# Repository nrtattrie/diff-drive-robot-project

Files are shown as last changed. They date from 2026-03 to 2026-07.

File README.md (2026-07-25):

# Diff-Drive Robot Project

A ROS 2 autonomous mobile robot project built in stages: differential-drive
navigation first, followed by a separately validated self-balancing controls
phase. The project emphasizes simulation, embedded motor control, encoder
odometry, sensor fusion, SLAM, Nav2, and disciplined hardware bring-up.

## Project Status

**Phase 1 — Foundation**

- Stage 1 software simulation is complete.
- The URDF, tf2 model, Gazebo Harmonic `DiffDrive`, and
  `ros2_control + diff_drive_controller` paths have been live-verified.
- Stage 2A hardware architecture is complete; Stage 2B now builds and validates
  the robot one subsystem at a time.
- A modular drivetrain deck follows one-channel acceptance. Final
  electronics-tier CAD remains gated on the two-channel, peripheral, and
  Pi-power checks.
- LiDAR and battery procurement remain deferred until the navigation hardware
  stage.

The historical hardware plan contained invalid assumptions, including treating
one Pololu `#2991` as a dual motor driver. Do not build from archived summaries
or the invalidated power diagram. See the
[component selection audit](hardware/component-selection-audit.md) and
[phase plan](docs/phases.md).

## Current Platform

### Compute and control

- Raspberry Pi 5, 8 GB
- Ubuntu 24.04 Desktop
- ROS 2 Jazzy
- NVMe boot through Raspberry Pi M.2 HAT+
- Arduino Due as the planned real-time motor/encoder controller
- Arduino Mega 2560 retained as a backup/prototyping controller

### Owned actuation and sensing

- 2× Pololu 50:1 37D 12 V gearmotors with 64 CPR encoders (`#4753`)
- 80 mm Pololu wheels and 6 mm mounting hubs
- Pololu Dual VNH5019 Motor Driver Shield (`#2507`) received for the two motor
  channels; physical identity was owner-accepted at B1, while assembly and
  powered bench acceptance remain pending
- 1× owned Pololu G2 High-Power Motor Driver 18v17 (`#2991`), reserved for
  later one-channel use rather than combined with the selected driver
- Adafruit BNO055 IMU
- Adafruit `#2998` bus-powered USB 2.0 hub, assigned to the BNO055/`#954`
  branch with the Due kept on a direct Pi port
- Raspberry Pi Camera Module 3
- HC-SR04 and other kit sensors for supplementary experiments
- RPLidar A1-class LiDAR planned for the autonomous-navigation stage

### Hardware constraints under validation

- Use commercial off-the-shelf boards, connectors, and wire. User soldering of
  supplied headers and ordinary wiring is acceptable; custom/professional
  assembly is outside the hobbyist project scope. Crimping is not assumed, so
  prefer solder, screw-terminal, lever-clamp, or pre-terminated connections as
  appropriate to the circuit.
- The encoders will use a regulated 5 V rail and one socketed Adafruit
  `74LVC245` product `#735` to translate their four outputs to the Due's 3.3 V
  hardware quadrature inputs; physical assembly and count-integrity bench
  acceptance remain pending.
- The Due will receive both power and serial through its Programming USB port,
  normally from the Pi, and will supply encoder 5 V and translator/driver-logic
  3.3 V. Bench current and reset behavior remain to be validated.
- Mobile Raspberry Pi power will use a protected 3S branch through the owned
  DROK set to 5.10 V and into the Pi 5 V/ground header; regulation, thermal,
  startup, and combined-load acceptance remain pending. Q8 selects one 10 A
  main fuse without additional branch-protection hardware. Q9 selects 16 AWG
  battery-side wiring, the 14 AWG inline fuse holder, continuity-checked
  ALITOVE distribution, and four short parallel Elegoo leads for Pi power;
  owned JST/STEMMA or Elegoo leads cover low-current wiring downstream of the
  Pi. The completed Q10 matrix fixes the final connection and pin allocation,
  while Stage 2B must reject any connection with excessive drop, heating,
  looseness, or reset behavior.
- The owned motors and 80 mm wheels are required Phase 2 reuse while plausible;
  preliminary dynamic screening supports that plausibility. All other Phase 2
  properties and reuse decisions remain intentionally deferred.

## Software Stack

- ROS 2 Jazzy on Ubuntu 24.04
- Gazebo Harmonic
- `ros2_control` and `diff_drive_controller`
- Nav2 and `slam_toolbox` planned for autonomous navigation
- `robot_localization` planned for encoder/IMU fusion
- Python for ROS integration and C++/Arduino code where real-time performance
  matters

## Repository Structure

```text
diff-drive-robot-project/
├── docs/                   Project architecture, phases, guides, and audits
├── hardware/               BOM, CAD exports, and hardware references
├── media/                  Images and other media
├── scripts/                Development and launch helpers
└── software/
    ├── arduino/            Embedded firmware
    └── ros2_ws/            ROS 2 workspace
```

## Build the ROS 2 Workspace

```bash
cd software/ros2_ws
colcon build
source install/setup.bash
```

For the verified simulation workflows, follow the
[Gazebo simulation quickstart](docs/gazebo_sim_quickstart.md).

## Roadmap

1. Execute the ordered Stage 2B assembly gates: Due and encoders, one motor
   channel, modular drivetrain, then both channels.
2. Validate the Pi/Due link, BNO055, camera, DROK, and complete Pi-power path.
3. Build the final electronics tier and tethered harness, then close the
   hardware gate with integrated and loaded thermal evidence.
4. Drive the real differential-drive robot and calibrate odometry.
5. Add LiDAR, SLAM, Nav2, and IMU fusion.
6. Model and validate the separate self-balancing conversion before committing
   Phase 2 hardware.

## Documentation

- [Architecture](docs/architecture.md)
- [Phase plan and task tracker](docs/phases.md)
- [Component selection audit](hardware/component-selection-audit.md)
- [Stage 2 hardware decision record](hardware/stage-2-hardware-decision-record.md)
- [Phase 1 power and signal interface matrix](hardware/power-signal-interface-matrix.md)
- [Stage 2 validation log](hardware/stage-2-validation-log.md)
- [Phase 2 preliminary dynamic model](hardware/phase-2-dynamic-model.md)
- [Gazebo simulation quickstart](docs/gazebo_sim_quickstart.md)
- [Assembly guide](docs/assembly.md)
- [Hardware BOM PDF](hardware/Bill%20of%20Materials%20-%20Sheet%20REV%2002.pdf)

## License

MIT License. See [LICENSE](LICENSE).

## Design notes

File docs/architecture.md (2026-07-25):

# Robot Architecture

## Directive for AI Assistants

This document is the canonical record of architectural decisions, technical
constraints, and design rationale. See [the phase plan](phases.md) for task
status, [the Stage 2 decision record](../hardware/stage-2-hardware-decision-record.md)
for selection evidence, and
[the interface matrix](../hardware/power-signal-interface-matrix.md) for exact
power, pin, connector, wire, threshold, and safe-state definitions.

Use this document before proposing or implementing changes. Do not modify it
unless explicitly asked. Do not treat archived summaries as current design
authority.

**Architecture status as of 2026-07-23:** Stage 2A is complete. The architecture
below is the selected design for the incremental Stage 2B build and
commissioning sequence. It is not yet a bench-validated final build. If a
statement here conflicts with the interface matrix, use the matrix for
connection-level details and resolve the discrepancy before wiring.

## Phase 1 System Overview

Phase 1 is an indoor differential-drive robot intended to progress from
tethered driving to encoder odometry, SLAM, and Nav2 autonomous navigation.

```text
Nav2 / teleop / ROS 2
          |
          v
   Raspberry Pi 5
      |       |---------------- Camera Module 3 (CSI-2)
      |       |---------------- #2998 hub -- BNO055 (USB-to-UART)
      |       `---------------- future RPLidar A1M8 (USB)
      |
      `--- USB serial + power ---> Arduino Due
                                      |
                         +------------+------------+
                         |                         |
                         v                         v
                  Dual VNH5019               encoder inputs
                    #2507                  through 74LVC245
                         |                         ^
                         v                         |
                    two #4753 motors --------------+
```

The Pi owns ROS 2, navigation, perception, and high-level velocity commands.
The Due owns real-time motor output, encoder counting, command-loss handling,
and motor-fault response. The Pi and Due communicate over one data-capable USB
connection to the Due Programming port.

## Selected Hardware Baseline

| Component | Selected role | Stage 2A state |
|---|---|---|
| Raspberry Pi 5, 8 GB | Primary computer running Ubuntu 24.04 and ROS 2 Jazzy | Owned; operating |
| 1 TB NVMe SSD and M.2 HAT+ | Pi boot and project storage | Owned; operating |
| Raspberry Pi Active Cooler | Pi thermal management through the dedicated fan connector | Owned; operating |
| Arduino Due | Real-time motor controller and hardware quadrature counter | Owned; bench integration pending |
| Pololu Dual VNH5019 shield `#2507` | Two-channel motor driver, separately mounted rather than stacked as a shield | Received; identity owner-accepted at B1; assembly/bench validation pending |
| 2x Pololu `#4753` 12 V, 50:1 gearmotors | Left and right Phase 1 drive, with integrated encoders | Owned |
| 80 mm Pololu wheels and 6 mm hubs | Drive wheels | Owned |
| Adafruit `74LVC245` `#735` and 20-pin socket | Four-channel 5 V-to-3.3 V encoder translation | Received; identity owner-accepted at B1; assembly/validation pending |
| Adafruit BNO055 `#4646` | IMU for later odometry fusion | Owned; UART validation pending |
| Adafruit USB Mini Hub with Power Switch `#2998` | Bus-powered expansion for the low-current BNO055/`#954` branch; three downstream sockets remain spare | Owned; integration validation pending |
| Raspberry Pi Camera Module 3 | Forward camera | Owned with Pi 5-compatible cable |
| DROK adjustable buck converter | Mobile Pi 5 V supply | Owned; exact-unit and loaded validation pending |
| Official Raspberry Pi 27 W USB-C supply | Bench/tethered Pi supply | Owned |
| RPLidar A1M8 development kit | Planned Phase 1 SLAM/Nav2 sensor | Deferred to Stage 4 |
| 3S battery, charger, and mating connector | Future mobile energy source | Deferred to Stage 4 |
| Pololu G2 18v17 `#2991` | Reserved one-channel driver; not part of the Phase 1 baseline | Owned |
| Arduino Mega 2560 | Backup/prototyping MCU only | Owned |

[BOM REV 02](../hardware/Bill%20of%20Materials%20-%20Sheet%20REV%2002.pdf)
is the accepted procurement snapshot. Procurement status does not constitute
bench validation.

## Power Architecture

### Selected topology

```text
future 3S battery (11.1 V nominal, 12.6 V full)
  |
  +-- keyed battery connector (manual disconnect)
  |
  +-- 10 A ATO/ATC fuse near battery positive
        |
        `-- ALITOVE distribution
              |
              +-- 16 AWG --> #2507 VIN/GND --> left/right motors
              |
              `-- 16 AWG --> DROK set to 5.10 V --> Pi 5 header
                                                        |
                                                        `-- USB --> Due
                                                                     |
                                                                     +-- 5 V --> both encoders
                                                                     `-- 3.3 V --> 74LVC245 and #2507 VDD
```

### Bench and mobile modes

- **Bench/tethered:** use the official 27 W USB-C supply for the Pi. The Pi
  powers and communicates with the Due over USB. A current-limited bench
  supply powers the motor-driver branch during staged testing.
- **Combined-path validation:** after dummy-load acceptance and before mobile
  use, the current-limited bench supply substitutes for the future 3S battery
  at the protected distribution input. In that controlled test only, the same
  distribution feeds `#2507` and the DROK/Pi header path so startup interaction
  and reset behavior can be measured without selecting the battery.
- **Mobile:** the protected 3S branch feeds the owned DROK. Set and verify the
  DROK at `5.10 V` before connecting the Pi, then feed Pi physical pins 2 and 4
  with two short, equal positive leads and grounds 6 and 14 with two short,
  equal return leads.
- Never connect Pi USB-C power and header power simultaneously.
- The Due receives power and serial only through its Programming USB port.
  Do not power it through `VIN`, the barrel jack, or its 5 V/3.3 V pins.
- Connect the Due to only one powered USB host at a time.

The mobile Pi path must sustain 5 A at the Pi header without excessive voltage
drop, heating, startup overshoot, undervoltage indication, or resets.
`PSU_MAX_CURRENT=5000` may be enabled only after that complete path passes
Stage 2B. The future RPLidar's conservative USB startup allocation makes this
validation a prerequisite for mobile LiDAR use.

### Protection boundary

- Use one 10 A main fuse; do not add branch fuses or a fused distribution
  board to the current design.
- Use the future battery's keyed/polarized connector as the normal manual
  disconnect. The owned 1 A toggle is not in the battery-current path.
- Do not add a separate emergency-stop switch, reverse-polarity board, or
  extra `#2507` bulk capacitor.
- The `#2507` supplies reverse-voltage, thermal, over/undervoltage, and
  output-short protection for its motor branch.
- Battery-specific undervoltage protection or monitoring remains deferred with
  the exact battery selection and is required before Stage 4 mobile operation.

## Motor Drive and Safe-State Policy

The `#2507` is used as a general-purpose board, not an Arduino shield. Solder
the three included 2-pin terminal blocks and a 13-pin logic header. Do not
install the Arduino stackable headers or the `ARDVIN=VOUT` jumper.

| Concern | Selected behavior |
|---|---|
| Motor channels | `M1` left motor; `M2` right motor; final polarity established unloaded |
| Logic supply | Due 3.3 V to driver `VDD`; common logic ground |
| PWM | Due hardware PWM at 20 kHz |
| Voltage limit | Initial 95% duty ceiling on a 12.6 V full 3S source, about 12.0 V average |
| Continuous-current target | Approximately 1.38 A per motor |
| Transient reference | 5.5 A is theoretical motor stall, not a permitted operating state |
| Normal stop | Bounded deceleration to zero wheel speed, then coast near standstill |
| Command loss | Recoverable 500 ms Due-side watchdog; zero target followed by coast |
| Driver fault | Either channel fault coasts both channels and latches motion off |
| Encoder stall | Calibrated lack of encoder progress coasts both and latches motion off |
| Reset state | Driver PWM pull-downs keep both outputs high-impedance; firmware establishes PWM LOW before accepting motion |
| Current sense | `M1CS/M2CS` directly to Due A0/A1 through the board's existing 10 kΩ resistors; no external clamp |

Current sensing is telemetry and diagnostic evidence, not the sole stall
trigger. Stage 2B must calibrate acceleration, near-zero coast transition,
stall-detection timing, ADC scaling, and loaded thermal behavior.

## Encoder Architecture

Both `#4753` encoders are powered from the Due's regulated 5 V output. Each
encoder can draw up to 10 mA and produces 0-5 V A/B signals, which must never
connect directly to the Due.

One socketed Adafruit `74LVC245` runs from Due 3.3 V and translates all four
encoder signals from its A side to its B side:

| Encoder signal | Translator | Due hardware input |
|---|---|---|
| Left A, yellow | A1 to B1 | D2 / `TIOA0` |
| Left B, white | A2 to B2 | D13 / `TIOB0` |
| Right A, yellow | A3 to B3 | D5 / `TIOA6` |
| Right B, white | A4 to B4 | D4 / `TIOB6` |

Set `DIR` high, `/OE` low, tie unused A5-A8 inputs to ground, leave unused
B5-B8 outputs open, and place one owned `104`/0.1 uF ceramic capacitor directly
between IC VCC and ground. The
[interface matrix](../hardware/power-signal-interface-matrix.md#74lvc245-fixed-wiring)
contains the complete 20-pin wiring.

## Arduino Due Pin Allocation

| Due resource | Assignment |
|---|---|
| D2, D13 | Left encoder A/B hardware quadrature pair |
| D5, D4 | Right encoder A/B hardware quadrature pair |
| D6, D7 | M1/M2 20 kHz hardware PWM |
| D8, D9 | M1 INA/INB direction |
| D10, D11 | M2 INA/INB direction |
| D22, D23 | M1/M2 EN/DIAG, configured as inputs only |
| A0, A1 | M1/M2 current sense through onboard 10 kΩ resistors |
| Programming USB | Pi serial communication and Due power |

The stock shield mapping and stock library pin assumptions are not
authoritative. Firmware must implement this allocation.

## Sensor and Peripheral Interfaces

| Device | Connection | Power and status |
|---|---|---|
| BNO055 | One black Pi USB 2.0 port through the bus-powered `#2998` hub to the owned Adafruit USB-to-TTL cable `#954`; BNO SDA/TX to cable white/RX, cable green/TX to BNO SCL/RX; BNO `3VO` strapped to `PS1` | Cable red 5 V to `VIN`, black to ground; keep hub switch on and external-power jack unused; owned, bench validation pending |
| Camera Module 3 | Pi CAM/DISP using the owned Standard-to-Mini cable: narrow 22-pin Pi end and wider 15-pin camera end | Pi-managed; owned |
| RPLidar A1M8 | Future development-kit USB adapter directly to a Pi USB port | Deferred purchase; include up to about 0.45 A working and 0.70 A startup in USB budget |

The owned INA219, APDS9960, HC-SR04, white terminal strips, and 1 A toggle have
no installed baseline function. Adding any of them requires
a defined interface and matrix revision. The HC-SR04 is not required for
Phase 1 navigation and its 5 V Echo output must not be connected directly to a
3.3 V input.

## Wiring, Grounding, and Assembly

- Use 16 AWG stranded copper for the battery trunk and both battery-side
  branches.
- Use the selected 14 AWG inline ATO/ATC holder with a 10 A fuse.
- Use the ALITOVE connectors only after continuity confirms the required
  internal topology. Tug-test every termination and reject any heating or
  loosening during Stage 2B.
- Land the battery feed and motor factory red/black leads directly in the
  `#2507` terminal blocks. Do not use JST-SH, STEMMA QT, Dupont, a breadboard,
  or the white terminal strips in a motor or battery-current path.
- The accepted Pi-power implementation uses two short, equal Elegoo positive
  leads and two short, equal ground leads, each no longer than about 12 inches.
  Their undocumented gauge/contact rating is an explicit Stage 2B rejection
  criterion.
- Use owned JST/STEMMA cables or Elegoo jumpers for low-current power and
  signals downstream of the Pi.
- Battery negative distributes separately to the driver power ground and DROK
  input ground. Motor return current must not pass through Pi, Due, encoder,
  translator, USB, or jumper-wire ground paths.
- Due, driver logic, translator, and both encoders share a logic reference.

The project uses commercial off-the-shelf products assembled by the user.
Soldering supplied headers and ordinary wiring is acceptable. Hired custom
assembly is outside scope, and crimping is not assumed.

## Software Architecture

- **OS/ROS:** Ubuntu 24.04 Desktop and ROS 2 Jazzy on the Pi 5.
- **Navigation:** Nav2 with `slam_toolbox`.
- **Drive integration:** `ros2_control` and `diff_drive_controller`; current
  configuration is validated in simulation, while physical hardware transport
  remains to be implemented.
- **Pi-to-Due transport:** custom 115200-baud, 8N1, newline-delimited ASCII
  protocol through `pyserial`, not micro-ROS. Commands are `ARM`, `DISARM`,
  `SET <left_cps> <right_cps>`, `STOP`, `RESET_FAULT`, and `STATUS`.
  Telemetry carries time, encoder totals/rates, current estimates, and
  state/fault flags. Parsing is length-, shape-, and range-checked; no
  application checksum or sequence layer is selected unless evidence shows it
  is needed over the ordered USB link.
- **Embedded wheel control:** the Due runs the Phase 1 wheel PI loops at
  200 Hz and emits commissioning telemetry at 20 Hz. A valid `SET` refreshes
  the recoverable 500 ms watchdog; driver and encoder-stall faults remain
  latched until an explicit safe reset.
- **Odometry:** wheel encoders first; later combine encoder odometry and BNO055
  IMU data through `robot_localization`.
- **Languages:** Python for ROS integration; C++/Arduino code where real-time
  behavior or performance requires it.

### Build commands

```bash
cd software/ros2_ws
colcon build
colcon build --packages-select <pkg>
source install/setup.bash
colcon test
colcon test --packages-select <pkg>
```

## Development Environment

- VS Code Remote SSH from the MacBook to the Pi.
- CAD on the MacBook in SolidWorks; 3D printing on the Bambu X1-C.
- CAD source files remain in Google Drive; repository hardware files are
  exported STL/STEP artifacts.
- Pi boots from the NVMe SSD and hosts the ROS 2 workspace.
- The Pi's desktop supports RViz, Gazebo, and `rqt`; Pi simulation should
  remain lightweight.

## Project Structure

- `docs/` — architecture, phases, guides, and historical session records.
- `hardware/` — current BOM, decision evidence, interface matrix, CAD exports,
  and datasheets.
- `software/ros2_ws/` — ROS 2 workspace and packages.
- `software/arduino/diffbot_due/` — evolving Due firmware.
- `software/arduino/tools/` — non-ROS commissioning utility.
- `scripts/` — project utilities.

## Phase 2 Reuse Boundary

The owned `#4753` motors, their encoders, and the 80 mm wheels/hubs are required
Phase 2 reuse while they remain plausible. The
[preliminary dynamic model](../hardware/phase-2-dynamic-model.md) found no
reason to replace them.

No other Phase 1 component, Phase 2 physical property, chassis decision,
controller choice, sensor, or power decision is assumed to transfer. Phase 2
self-balancing remains a separate later design exercise and does not constrain
unfinished Phase 1 choices.

## Stage 2B Build and Validation Boundary

Stage 2A selected a coherent architecture; it did not prove the actual
hardware. Stage 2B now combines construction, firmware, CAD, and validation in
one downstream sequence. The [phase plan](phases.md) owns its 28 approval
gates, the [assembly guide](assembly.md) owns the reusable procedure, and the
[validation log](../hardware/stage-2-validation-log.md) owns measured evidence.

Stage 2B must:

1. accept the physical inventory, current-limited supply, dummy-load fixture,
   and measurement boundary before powered assembly;
2. bring up the Due, serial safety state machine, 20 kHz PWM, translator, and
   both encoders before motor power;
3. validate one unloaded motor/encoder channel, closed-loop PI control, reset
   safety, the 500 ms watchdog, and non-destructive fault/stall responses;
4. permit a modular drivetrain deck only after the one-channel gate, then
   validate both mounted channels and low-speed tethered motion;
5. validate Pi/Due USB, BNO055, camera, the DROK, and the complete 5 A Pi
   header path before final electronics-tier CAD;
6. build only the accepted final tethered harness and mounting layout, then
   pass integrated raised and loaded thermal regressions; and
7. synchronize calibrated firmware, CAD exports, URDF/controller nominal
   geometry, architecture, matrix, and phase evidence before closing the
   hardware gate.

No gate may claim measurements outside the available instrument bandwidth.
In particular, the Due D3 PWM loopback is an internal commissioning check, and
ordinary multimeter readings do not establish high-speed transient behavior.

## Deferred Decisions

- Exact 3S battery chemistry/capacity, charger, keyed connector SKU, and
  undervoltage method: Stage 4.
- RPLidar A1M8 purchase: Stage 4.
- Battery/LiDAR mounting details remain provisional envelopes in Stage 2B;
  their exact mounting is completed with those deferred components in Stage 4.
- Any optional HC-SR04, APDS9960, or INA219 integration: only if a demonstrated
  need appears. The owned `#2998` hub is now assigned only to the BNO055 branch.
- Phase 2 mass distribution, center of mass, inertia, controller, IMU
  suitability, power system, and chassis: Phase 2 work, not Phase 1 scope.

## Explicitly Superseded Claims

The following statements in archived summaries are invalid and must not be
reintroduced:

- one Pololu `#2991` is a dual motor driver;
- the `#4753` encoders can be powered from Due 3.3 V;
- a 5.1 V supply is valid for Due `VIN`;
- the Due or Pi should be powered from the `#2507`;
- thin JST-SH/STEMMA/Dupont leads are acceptable for motor or battery power;
- the owned 1 A toggle is the robot's battery switch; or
- a Phase 1 hardware choice is automatically proven suitable for the unbuilt
  Phase 2 robot.

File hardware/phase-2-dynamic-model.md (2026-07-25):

# Phase 2 Preliminary Dynamic Model

**Status:** Phase 1 Stage 2A Q2 complete; preliminary screening supports the
required reuse of the owned motors and wheels

**Started:** 2026-07-22

This document is the engineering record for the preliminary Phase 2
self-balancing model. It tracks physical properties, evidence, assumptions,
equations, screening calculations, uncertainty, and the narrow Q2 reuse
decision. It is not an assembly guide, a final controller design, or proof that
the physical robot will balance.

The reproducible calculation is
[`scripts/phase2_dynamic_model.py`](../scripts/phase2_dynamic_model.py).
Accepted system decisions belong in `docs/architecture.md` only after the
required review and bench evidence.

## Q2 Decision

Q2 answers two narrow questions:

1. Do the owned motors and 80 mm wheels have a plausible Phase 2 operating
   envelope across reasonable body mass, center-of-mass, and inertia ranges?
2. Given Nathan's requirement not to replace plausible motors or wheels, should
   those owned components be fixed as required Phase 2 reuse?

The answer to both is yes. The owned `#4753` motors and 80 mm wheels remain
plausible in this preliminary screen and are required reuse unless later
physical evidence demonstrates that they are infeasible.

Q2 does not select or size a motor driver, decide whether any other Phase 1
component must transfer to Phase 2, freeze chassis geometry, or establish final
Phase 2 physical properties. Q3 is a separate later task.

Documented balancing platforms such as Pololu's
[Balboa](https://www.pololu.com/docs/0J70/all) use ordinary bidirectional
brushed DC gearmotors with encoder feedback rather than requiring hobby RC
servos. This supports the general motor class already selected, but it does not
prove the owned units' final suitability: gearbox backlash, thermal behavior,
installed mass properties, traction, and closed-loop disturbance recovery
remain Phase 2 validation questions.

The model is deliberately a range study. No Phase 2 chassis exists yet, so the
body properties below are illustrative scenarios rather than requirements or
facts that must be resolved during Phase 1.

## Evidence States

Every property is assigned one of these states:

- **Manufacturer:** published by the component manufacturer.
- **Measured:** physically measured on the owned component or assembly.
- **Assumed:** a scenario value chosen to explore the design space.
- **Derived:** calculated from stated manufacturer, measured, or assumed inputs.
- **Bench-validated:** demonstrated in the intended electrical and mechanical
  interface.

Agreement in a chat does not change a property's evidence state.

## Physical-Property Register

### Running gear and motor

| Property | Symbol | Value or range | Unit | Evidence | State |
|---|---|---:|---|---|---|
| Motor SKU and quantity | - | 2x Pololu `#4753` | - | Owned inventory and product page | Manufacturer; ownership recorded |
| Nominal motor voltage | `V_nom` | 12 | V | Pololu product page | Manufacturer |
| Gear ratio | `N` | 50:1 | - | Pololu product page | Manufacturer |
| No-load output speed at 12 V | `n_0` | 200 | rpm | Pololu product page and performance curve | Manufacturer |
| No-load current at 12 V | `I_0` | 0.08-0.20 | A | Performance-curve fit says 0.080 A; catalog table says 0.20 A | Manufacturer discrepancy; bracketed |
| Stall output torque at 12 V | `tau_stall` | 21 kgf·cm = 2.059 | N·m | Pololu catalog; theoretical extrapolation | Manufacturer; not an operating point |
| Stall current at 12 V | `I_stall` | 5.4-5.5 | A | Performance curve and product page | Manufacturer; theoretical extrapolation |
| Maximum-efficiency point | - | 180 rpm, 2.2 kgf·cm, 0.66 A | - | Pololu product page | Manufacturer |
| Gearmotor mass, each | - | 0.205 | kg | Pololu product specifications | Manufacturer; verify owned units |
| Encoder resolution | - | 3200 counts/output revolution | counts/rev | 64 CPR at motor shaft times 50:1 ratio | Manufacturer/derived |
| Wheel SKU and quantity | - | 2x Pololu `#1430` | - | BOM and product page | Manufacturer; ownership recorded |
| Wheel radius | `r` | 0.040 | m | 80 mm nominal diameter | Manufacturer; loaded radius unmeasured |
| Wheel mass, each | `m_w` | 0.0198 | kg | Pololu specifies 0.7 oz including tire | Manufacturer |
| Hub SKU and quantity | - | 2x Pololu `#1083` | - | BOM and product page | Manufacturer; ownership recorded |
| Hub mass, each | `m_h` | 0.0068 | kg | Pololu product specifications | Manufacturer |
| Wheel rotational inertia | `J_w` | wheel as thin hoop; hub as solid disk | kg·m² | Conservative geometry approximation | Assumed/derived |
| Combined wheel/hub rotational inertia | `J_running` | 6.46e-5 | kg·m² | Geometry approximation above | Derived |
| Equivalent running-gear axle mass | - | 0.0937 | kg | Translating mass plus `J_running/r^2` | Derived |
| Gearbox backlash and friction | - | unknown | - | No owned-unit test | Unresolved |
| Reflected motor/gear inertia | - | omitted | kg·m² | Not published for the owned gearmotor | Unresolved model omission |

The 0.205 kg gearmotor bodies are part of the balancing body, not the rotating
wheel mass. Their location near the axle can reduce their contribution to body
center-of-mass height, but their exact installed position and inertia remain
unmeasured.

### Illustrative body and operating scenarios

| Property | Symbol | Value or range | Unit | Evidence | State |
|---|---|---:|---|---|---|
| Balancing-body mass, excluding wheels/hubs | `m` | 1.0-2.0 | kg | Preliminary design scenarios | Assumed |
| Body center of mass above axle | `l` | 0.08-0.20 | m | Preliminary design scenarios | Assumed |
| Body pitch inertia about its center of mass | `I_b` | `k m l^2`, `k` = 0.25-0.60 | kg·m² | Distributed-body scenario model | Assumed/derived |
| Low motor-terminal voltage | `V_low` | 9.6 | V | Sensitivity case only; battery architecture is unresolved | Assumed |
| Nominal modeled motor-terminal voltage | `V_nom` | 12.0 | V | Motor rating | Manufacturer/model boundary |
| Tire/floor friction coefficient | `mu` | unknown | - | No traction test | Unresolved |

The 9.6 V case is not a battery cutoff decision. It is a deliberately reduced
motor-terminal-voltage case used to expose wheel-speed sensitivity. It does not
set a battery, power-system, or motor-driver requirement.

## Planar Model

The initial model covers straight fore-aft balancing only. Left and right motor
torques are assumed equal, so yaw is omitted.

```text
                    body center of mass
                             o
                             |  l
                             |
                             |  theta
                  -----------+----------- body
                             O  wheel axle  ---> x
                            / \
                           O   O            radius r

             two motor torques -> total output torque T
```

The body is one rigid mass attached to the wheel axle. Unlike a simple force-on-
cart shortcut, this model includes both effects of geared motor output torque:

- `T/r` produces fore-aft tractive force through the rolling wheels;
- `-T` is the equal and opposite reaction torque applied to the body.

That reaction term is important for a real two-wheeled balancing robot.
With positive wheel rotation defined in the forward-rolling direction, the
ideal motor's virtual work is:

```text
delta W = T delta(x/r - theta)
```

The corresponding generalized inputs are therefore `T/r` in translation and
`-T` in body pitch. This is the sign and scale used by the script.

Define:

- `x`: axle displacement in meters;
- `theta`: body pitch from upright in radians, positive in the forward direction;
- `T`: total output torque from both motors in N·m;
- `A = m + m_running + J_running/r^2`;
- `B = m l`;
- `C = I_b + m l^2`.

With ideal rolling and equal motor torques, the nonlinear planar equations used
as the starting point are:

```text
A x_ddot + m l cos(theta) theta_ddot
  - m l sin(theta) theta_dot^2 = T/r

m l cos(theta) x_ddot + C theta_ddot
  - m g l sin(theta) = -T
```

Linearizing about upright (`theta = 0`) gives:

```text
[ A  B ] [x_ddot    ] = [ T/r                 ]
[ B  C ] [theta_ddot]   [ m g l theta - T     ]
```

The mass-matrix determinant is:

```text
D = A C - B^2
```

With zero motor torque, the positive open-loop pole is:

```text
lambda = sqrt(A m g l / D)
```

Its inverse is the open-loop e-fold time. It is a useful indication of how fast
small tilt errors grow, not a complete sampling-rate requirement.

### Screening recovery maneuver

The calculation uses a 10-degree lean from rest and an ideal symmetric angular
acceleration/deceleration maneuver lasting 0.30 seconds. For that screening
maneuver, the initial target acceleration magnitude is:

```text
theta_ddot_target = -4 theta / t_recovery^2
```

The corresponding initial total torque is:

```text
T = (A m g l theta - D theta_ddot_target) / (A + B/r)
```

This is an initial-condition envelope calculation, not a simulated controller.
It does not claim that constant acceleration, perfect state information, or the
ideal trajectory can be achieved by the physical robot.

## Motor Curve Treatment

Pololu's current sources do not agree exactly. The product table reports
0.20 A no-load and 5.5 A theoretical stall, while the performance-curve fit
prints:

```text
current [A] = 0.080 + 0.026 torque [kgf·mm]
```

The script therefore reports a current range bounded by:

1. the published performance-curve fit; and
2. a straight line through the more conservative catalog no-load and stall
   endpoints.

The published 12 V speed fit is:

```text
speed [rpm] = 200 - 1.0 torque [kgf·mm]
```

For the 9.6 V sensitivity case, no-load speed is scaled linearly with voltage
while the published torque slope is retained. Motor heating, winding
temperature, PWM behavior, battery sag, and unit-to-unit variation are not
represented.

## Screening Scenarios and Results

The scenario labels are not chassis proposals:

| Scenario | Body mass | CoM height | Inertia ratio `k` |
|---|---:|---:|---:|
| Compact / fast-fall | 1.0 kg | 0.08 m | 0.25 |
| Nominal | 1.5 kg | 0.14 m | 0.333 |
| Tall / heavy | 2.0 kg | 0.20 m | 0.60 |

Command used:

```bash
python3 scripts/phase2_dynamic_model.py
```

For a 10-degree lean, 0.30-second ideal recovery, and 9.6 V low-voltage
sensitivity case:

| Scenario | Open-loop pole | E-fold time | Torque / motor | Current estimate | Peak wheel speed | Demand | Available at 9.6 V | Traction `mu` |
|---|---:|---:|---:|---:|---:|---:|---:|---:|
| Compact / fast-fall | 19.1 rad/s | 52 ms | 0.027 N·m | 0.15-0.27 A | 0.27 m/s | 65 rpm | 157 rpm | 0.13 |
| Nominal | 13.4 rad/s | 75 ms | 0.052 N·m | 0.22-0.33 A | 0.40 m/s | 95 rpm | 155 rpm | 0.17 |
| Tall / heavy | 8.7 rad/s | 115 ms | 0.094 N·m | 0.33-0.44 A | 0.56 m/s | 133 rpm | 150 rpm | 0.23 |

The traction column is the ideal minimum tire/floor coefficient implied by the
initial per-wheel torque and static normal-load split. Dynamic load transfer is
omitted.

### Sensitivity finding

For the tall/heavy case, shortening the same ideal recovery to 0.15 seconds
demands approximately 191 rpm while the first-order motor curve predicts only
about 140 rpm available at 9.6 V and 180 rpm at 12 V at the required torque.
That case is speed-infeasible even though its estimated current remains below
0.8 A.

This is why Phase 2 cannot be reduced to a stall-torque margin. Within this
preliminary envelope, wheel-speed headroom, body geometry, traction, and
unmodeled drivetrain behavior can matter before raw motor current.

## Interpretation

### What the model supports

- The owned `#4753` motors and 80 mm wheels are plausible Phase 2 hardware
  across the three illustrative screening cases.
- Nathan requires those motors and wheels to be reused while they remain
  plausible. This screen found no reason to replace them, so no new motors or
  wheels are planned.
- The examined 0.30-second recovery cases require approximately 0.15-0.44 A per
  motor by the two manufacturer-data fits. This is below the published 0.66 A
  maximum-efficiency current and well below the approximately 1.38 A general
  25%-of-stall continuous planning guideline.
- A lower center of mass is not automatically easier to balance. The compact
  scenario has the shortest open-loop e-fold time because its geometry falls
  faster even though it requires less torque.

### What the model does not support

- It does not prove that the motors and wheels will balance the eventual real
  robot; that requires the real Phase 2 design and physical tests.
- It does not validate a specific center-of-mass height or chassis shape.
- It does not capture gearbox backlash, drivetrain compliance, reflected motor
  inertia, motor inductance, rolling resistance, tire deformation, saturation
  recovery, yaw, or impacts.
- Its current and speed results are screening outputs, not requirements for Q3
  or any other Phase 1 hardware decision.

## Q2 Reuse Boundary

Nathan approved this narrow boundary:

| Component or subsystem | Q2 decision | Scope |
|---|---|---|
| Two Pololu `#4753` motors, including their integrated encoders | **Required reuse while plausible** | The preliminary model supports plausibility. Replacement is considered only if later physical Phase 2 evidence demonstrates infeasibility. |
| 80 mm Pololu wheels and 6 mm hubs | **Required reuse while plausible** | The preliminary model supports plausibility. No new wheel size is being planned. |
| Every other Phase 1 component or subsystem | **Not decided by Q2** | Select and validate it for Phase 1 on Phase 1 requirements. Phase 2 reuse may be considered later without constraining current work. |

This decision does not promise that the entire Phase 1 platform will transfer
unchanged. It fixes only the motors and wheels because Nathan explicitly
requires their reuse and the preliminary model found them plausible.

## Intentionally Deferred Phase 2 Properties

Actual Phase 2 mass, center of mass, inertia, chassis geometry, control design,
sensor behavior, drivetrain losses, backlash, traction, thermal behavior, and
disturbance-recovery targets are unknown because Phase 2 has not been designed
or built. They are intentionally deferred to Phase 2 and do not block Q2 or the
remaining Phase 1 work.

## Reproducibility and Checks

Run:

```bash
python3 scripts/phase2_dynamic_model.py --self-test
python3 scripts/phase2_dynamic_model.py
python3 scripts/phase2_dynamic_model.py --recovery-time 0.15
```

The self-test checks manufacturer-point conversions, brackets the published
maximum-efficiency current, verifies a positive mass matrix, confirms all three
baseline cases retain low-voltage speed headroom, and confirms that the
aggressive tall/heavy case exceeds it.

## Primary Sources

- [Pololu `#4753` product specifications](https://www.pololu.com/product/4753)
- [Pololu 37D gearmotor performance curves](https://www.pololu.com/file/0J1736/pololu%E2%80%9037d%E2%80%90metal%E2%80%90gearmotors%E2%80%90rev%E2%80%901%E2%80%902.pdf)
- [Pololu `#1430` 80x10 mm wheel specifications](https://www.pololu.com/product/1430/specs)
- [Pololu `#1083` 6 mm hub specifications](https://www.pololu.com/product/1083/specs)
- [MIT Underactuated Robotics cart-pole dynamics and linearization](https://underactuated.mit.edu/acrobot.html#cart_pole)
- [University of Michigan inverted-pendulum equation derivation](https://ctms.engin.umich.edu/CTMS/index.php?example=InvertedPendulum&section=SystemModeling)
- [Pathak, Franch, and Agrawal: wheeled-inverted-pendulum dynamics with motor-torque inputs](https://doi.org/10.1109/TRO.2004.840905)

The cart-pole sources support the rigid-body and linearization structure. The
motor reaction torque in this document follows from actuator work between the
wheel and body coordinates and is retained explicitly for the two-wheeled
robot.

## Revision History

| Date | Change | Evidence state |
|---|---|---|
| 2026-07-22 | Created Q2 property register, planar model, sensitivity cases, current envelope, and proposed reuse boundary | Manufacturer data plus assumed scenarios; no physical validation |
| 2026-07-22 | Corrected Q2 scope: motors and wheels are required reuse while plausible; all other Phase 2 properties and reuse decisions are deferred | User-approved planning constraint supported by preliminary screening |

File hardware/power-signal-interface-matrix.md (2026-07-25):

# Phase 1 Power and Signal Interface Matrix

**Status:** Q10 complete as a Stage 2A design definition. No connection in this
document is considered electrically validated until it passes the applicable
Stage 2B gate in the [assembly guide](../docs/assembly.md) and
[validation log](stage-2-validation-log.md).

**Last reviewed:** 2026-07-25

This is the authoritative connection-level companion to the
[Stage 2 hardware decision record](stage-2-hardware-decision-record.md). It
turns Q3-Q9 into one buildable pin, power, wire, protection, and safe-state
definition without changing the decisions already made there.

## Scope and Rating Convention

The active Phase 1 baseline includes the battery interface, protected power
distribution, DROK, Raspberry Pi 5, Arduino Due, `#2507`, both `#4753` motors
and encoders, the `74LVC245`, owned Adafruit `#2998` USB hub, BNO055, Camera
Module 3, installed M.2/NVMe and Active Cooler assemblies, and the planned
RPLidar A1M8 development kit.

- A **normal ceiling** is a design or manufacturer limit, not a prediction
  that the device always draws that current.
- A **transient ceiling** is shown where the manufacturer supplies one or a
  conservative system case can be calculated. It is not permission to operate
  continuously at that value.
- Logic signal wires do not carry load power. Their current is input/pull-up
  current only and is described as `logic-only`.
- Values marked **validate** are commissioning evidence, not undecided
  architecture. Stage 2B must measure them.
- `M1` is assigned to the left motor and `M2` to the right motor. The unloaded
  direction test establishes which terminal polarity produces positive wheel
  motion.

The owned INA219, APDS9960, HC-SR04, `#2991`, white terminal strips, and 1 A
toggle are not installed in the baseline matrix. Adding one later
requires a matrix revision and a defined power/interface budget. The battery
connector and undervoltage method remain battery-selection-dependent Stage 4
items.

## System Topology

```text
3S battery
  |
  +-- keyed connector -- 10 A ATO/ATC fuse -- ALITOVE distribution
                                                   |
                                                   +-- #2507 -- M1/M2
                                                   |
                                                   +-- DROK 5.10 V -- Pi 5
                                                                          |
                                                                          +-- USB -- Due
                                                                          |          |
                                                                          |          +-- encoders, 5 V
                                                                          |          +-- LVC245/#2507 VDD, 3.3 V
                                                                          |
                                                                          +-- USB -- #2998 hub -- USB-TTL -- BNO055
                                                                          +-- CAM/DISP -- Camera 3
                                                                          +-- USB -- future RPLidar A1
```

Bench mode replaces the battery/DROK feed to the Pi with the official 27 W
USB-C supply. Never connect the Pi's USB-C supply and 5 V header feed at the
same time.

## Power Interface Matrix

| ID | Source to load; direction and channels | Voltage | Maximum normal / transient current | Connector and wire | Protection and shutdown state | Controller |
|---|---|---:|---:|---|---|---|
| P0 | Official 27 W supply to Pi; power, 1 branch, bench only | 5.1 V | 5 A supply ceiling / supply-managed | Official USB-C cable | Official supply protection; unplug to isolate; mutually exclusive with P6 | Pi power management |
| P1 | Future 3S battery to fused distribution; power, 1 trunk | 11.1 V nominal, 12.6 V full; low endpoint deferred with battery | About 6.8 A normal design budget; theoretical short transient can approach 15 A before protection | Future keyed/polarized battery mate, 16 AWG copper, selected 14 AWG inline holder, ALITOVE junction | 10 A ATO/ATC fuse nearest practical point to battery positive; keyed connector is manual disconnect; undervoltage policy required before Stage 4 | User disconnect; fuse |
| P2 | Fused distribution to `#2507 VIN/GND`; power, 1 branch | 3S battery range | 2.76 A combined normal target / 11 A combined theoretical motor stall | 16 AWG copper into `#2507` 5 mm terminal; common battery-negative junction | Main 10 A fuse plus driver reverse-voltage, thermal, over/undervoltage, and short protection; Due commands coast | Due and `#2507` |
| P3 | `#2507 M1A/M1B` to left `#4753`; bidirectional motor power, 1 channel | PWM from 3S; initial average ceiling about 12.0 V at 95% duty on 12.6 V | 1.38 A normal target / 5.5 A theoretical stall | Motor factory red/black leads, removed from the shared housing or cut/stripped, directly into M1 terminal | Driver protection; command watchdog, fault, or detected stall causes both channels to coast | Due M1 control |
| P4 | `#2507 M2A/M2B` to right `#4753`; bidirectional motor power, 1 channel | Same as P3 | 1.38 A normal target / 5.5 A theoretical stall | Motor factory red/black leads directly into M2 terminal | Same as P3 | Due M2 control |
| P5 | Fused distribution to DROK input; power, 1 branch | 3S battery range, subject to exact-unit input check | Allocate no more than 4 A normal to support a 25.5 W output with conversion loss; startup transient must remain inside the validated converter/main-fuse path | 16 AWG copper into the exact unit's input terminals | Main 10 A fuse; secure adjustment after setting; keyed disconnect removes input | DROK regulation; user disconnect |
| P6 | DROK output to Pi 5 header; power, 1 branch over 4 conductors | 5.10 V set point; validate at Pi header under load | 5 A path ceiling / startup included in Stage 2B load test; approximately 2.5 A per positive and return lead if sharing is even | Four equal, short Elegoo leads through one owned 23 mm 2x20 GPIO extender: positives to physical pins 2/4 and returns to 6/14; each at most about 12 in; cut/strip the DROK ends and verify the actual header/jumper mating sex | No USB-C power simultaneously; reject on polarity error, excessive drop, heating, undervoltage, or reset; main fuse upstream | DROK and Pi power management |
| P7 | Pi USB-A to Due Programming port; power and data, 1 branch | USB 5 V | Conservative 500 mA branch ceiling / USB-managed | One data-capable USB-A-to-micro-B cable | Due USB polyfuse; Pi USB current budget; power loss/reset leaves motor PWM pulled low and motors coasting | Pi USB host; Due |
| P8 | Due 5 V output to both motor encoders; power, 2 loads | Regulated 5 V | 10 mA per encoder, 20 mA combined / same manufacturer maximum | Factory blue/green conductors retained in each 1x6/2.54 mm housing where practical, mating marked male header segments on the Mega-prototype carrier; short soldered carrier wiring and owned jumpers complete the fanout | Inside P7 ceiling; never connect encoder supply to motor battery | Due USB branch |
| P9 | Due 3.3 V output to `74LVC245 VCC` and `#2507 VDD`; power, 2 loads | 3.3 V | Allocate 20 mA combined / 20 mA; far below the Due rail's 800 mA rating | Owned male-to-female Dupont lead to the `#2507`; short jumper/soldered wiring on the owned Mega Prototype Shield V3 carrier; `0.1 uF` ceramic directly across LVC245 pins 20 and 10 | Inside P7 ceiling; P9 loss removes EN/DIAG pull-ups while P7 loss also releases PWM to its board pull-down | Due regulator |
| P10 | Pi USB through owned bus-powered Adafruit `#2998` hub and owned `#954` cable to BNO055 `VIN/GND`; power, 1 load | 5 V input; BNO board creates 3.3 V internally | 50 mA BNO allocation plus uncharacterized hub overhead; cable power output is rated 500 mA | `#2998` captive USB-A lead to one black Pi USB 2.0 port; hub port 1 to `#954`; `#954` red to `VIN`, black to `GND`, using soldered BNO 0.1 in male header | Included in Pi USB budget; keep hub switch on in operation; leave its external DC jack unused; Pi shutdown or hub switch/cable removal powers sensor off | Pi USB host and hub switch |
| P11 | Pi CAM/DISP connector to Camera Module 3; power and data, 1 interface | Pi-managed camera rails; 3.3 V control | Allocate 0.5 A equivalent within the Pi's 5 V whole-system budget for normal/transient planning; the camera connector itself is Pi-managed, not a user-wired power branch | Use the owned **Standard-to-Mini** cable supplied in the camera bag: 22-pin, 0.5 mm Pi end to 15-pin, 1 mm camera end; verify the unequal ends before insertion | Pi camera power-enable and driver shutdown; power removed with Pi | Pi camera subsystem |
| P12 | Pi USB to future RPLidar A1M8 development-kit USB adapter; power and data, 1 branch | 5 V | Up to about 450 mA working (350 mA scanner plus 100 mA motor) / up to about 700 mA startup (600 mA scanner plus 100 mA motor) | Buy the development kit with its USB adapter/cable; connect directly to one blue Pi USB 3.0 port rather than the hub | Included in the validated Pi USB total; stop scanning in software before shutdown; Pi power loss stops unit | Pi USB host and ROS driver |

P1's theoretical transient combines both 5.5 A motor stall values and the 4 A
DROK input allocation. It is a fault-envelope calculation, not a normal load.
The 10 A fuse protects the main harness according to the selected fuse's
time-current behavior; it is not a precise electronic current limiter.

The conservative named-device Pi USB startup allocation is `0.50 A` for the
Due branch, `0.05 A` for the BNO055, and `0.70 A` for the future RPLidar, or
`1.25 A`, plus the `#2998`'s uncharacterized self-consumption. The Pi 5 fan
header shares the downstream peripheral-current budget, so the Active Cooler
must also be present during the combined test. This arrangement is permitted
only with the Pi's `1.6 A` budget from a recognized or deliberately configured
5 A source. The RPLidar may not be added to the mobile configuration until
Q7's full 5 A validation and `PSU_MAX_CURRENT=5000` enablement have passed.
The hub adds communication ports, not current capacity; leave its 1.35 mm
external-power jack unused.

## Signal Interface Matrix

The Due is a 3.3 V-only controller. Its digital input limits at a 3.3 V supply
are approximately `LOW <= 0.99 V` and `HIGH >= 2.31 V`. No 5 V encoder signal
may bypass the translator.

| ID | Source to destination; direction and channels | Levels, thresholds, and rate | Signal current | Connector and wire | Protection and shutdown state | Controller |
|---|---|---|---|---|---|---|
| S1 | Pi USB host to/from Due Programming port; bidirectional, 1 serial link | USB-managed electrical levels; 115200 baud, 8N1, newline-delimited ASCII; signed left/right targets in encoder counts/s; state telemetry at 20 Hz | USB signal-only; P7 carries power | P7 data-capable USB cable | Strict length/shape/range parsing; boot disarmed; only valid `SET` refreshes the recoverable 500 ms watchdog; stale/invalid traffic leads to zero target and coast; driver/stall faults latch until a safe explicit reset | Pi ROS bridge and Due firmware |
| S2 | Due D6 to `M1PWM`, and D7 to `M2PWM`; Due to driver, 2 channels | 0/3.3 V; driver `LOW <= 0.9 V`, `HIGH >= 2.1 V`; 20 kHz hardware PWM | Logic-only | `#2507` board-supplied 2.54 mm male logic header and owned Elegoo male-to-female leads: male into Due, female onto driver | `#2507` pulls PWM low by default, making outputs high impedance; firmware configures both low before other motor pins | Due hardware PWM |
| S3 | Due D8/D9 to `M1INA/M1INB`, and D10/D11 to `M2INA/M2INB`; Due to driver, 4 channels | 0/3.3 V; same driver thresholds as S2 | Logic-only | Same header/lead class as S2 | Direction inputs float during reset, but PWM's hardware-low default keeps outputs coasting; firmware sets direction only after PWM is low | Due GPIO |
| S4 | `M1EN/DIAG` to Due D22 and `M2EN/DIAG` to D23; driver to Due, 2 channels | Normal HIGH pulled to 3.3 V by P9; driver fault LOW; Due thresholds above | Logic-only; pull-up current only | Same header/lead class as S2 | Configure Due pins as **inputs only**. Either LOW disables that hardware channel; firmware responds by coasting both and latching motion off | `#2507` fault hardware and Due |
| S5 | `M1CS` to Due A0 and `M2CS` to A1; driver to Due, 2 analog channels | About 0.140 V/A while driving: about 0.193 V at 1.38 A and 0.77 V at the motor's 5.5 A theoretical stall; 3.3 V would correspond to about 23.6 A | Signal-only in the intended range; the board's existing 10 kΩ series resistor limits abnormal input current to at most a few hundred microamps | Owned male-to-female Dupont leads from the `#2507` male header to A0/A1; no added clamp components | Pololu considers the 10 kΩ-isolated outputs generally safe for 3.3 V MCU inputs. No external clamp is required for these 5.5 A-stall motors; reconsider only if the motor/current envelope changes. Firmware treats current as telemetry; fault/stall policy commands coast | Due ADC and firmware |
| S6 | Left encoder yellow/white to LVC245 A1/A2 and right yellow/white to A3/A4; encoder to translator, 4 channels | 0/5 V; LVC245 at 3.3 V accepts `LOW <= 0.8 V`, `HIGH >= 2.0 V`; up to about 2.67 kHz per channel at 200 rpm | Logic-only | Factory conductors retained in each 1x6 housing where practical, mated to marked male header segments soldered on the translator carrier after cavity-order verification | Translator prevents 5 V reaching Due; loss of valid encoder progress under a motion command invokes the calibrated stall response | Motor encoders |
| S7 | LVC245 B1/B2 to Due D2/D13 and B3/B4 to D5/D4; translator to Due, 4 channels | 0/3.3 V; output meets Due thresholds; up to about 10.67 k count events/s per motor in full quadrature at 200 rpm | Logic-only | `#735` in one `#2204` socket on the owned Mega Prototype Shield V3; short carrier wiring and owned male-ended Dupont leads to Due | `/OE` is permanently low; DIR permanently high; P9 loss removes outputs; firmware count-integrity checks support stall detection | Due timer-counter quadrature blocks |
| S8 | BNO055 SDA (UART TX) to `#954` white (RX into USB), and `#954` green (TX out) to BNO055 SCL (UART RX); bidirectional UART as 2 unidirectional channels, with the `#954` USB end on `#2998` port 1 | BNO breakout and cable use compatible 3.3 V logic; USB 2.0 upstream; 115200 baud, 8N1 on the UART side | Logic-only | `#2998` to `#954` USB-A; soldered BNO 0.1 in male header to the cable's individual female sockets | Keep the hub switch on; Pi/driver timeout marks lost IMU data invalid; power loss stops sensor; no motor-safety behavior depends solely on IMU | Pi ROS BNO055 driver |
| S9 | BNO055 `3VO` to `PS1`; fixed sensor-mode strap, 1 channel | 3.3 V HIGH selects UART while `PS0` remains at its default LOW state | Logic-only | One owned female-to-female Elegoo/Dupont jumper at the BNO header | Fixed configuration; do not connect the STEMMA I2C bus simultaneously | Hardware strap |
| S10 | Camera Module 3 to/from Pi CAM/DISP; camera to Pi data plus bidirectional control, 1 CSI-2 interface | Two MIPI CSI-2 data lanes and clock; Pi-managed 3.3 V control | Signal-only; P11 carries module power | P11 22-to-15-pin FFC | Pi camera driver controls enable and streaming; stop capture before shutdown | Pi camera subsystem |
| S11 | Future RPLidar development-kit USB adapter to/from Pi; bidirectional, 1 serial/USB link | USB-managed externally; scanner-side UART is handled by supplied adapter | USB signal-only; P12 carries power | Supplied development-kit USB cable | ROS driver commands scan/motor stop; stale scans are rejected by navigation software | Pi and RPLidar ROS driver |

## Arduino Due Pin Allocation

| Due resource | Assignment | Required startup configuration |
|---|---|---|
| D2 / `TIOA0` | Left encoder A from LVC245 B1 | Hardware quadrature input |
| D13 / `TIOB0` | Left encoder B from LVC245 B2 | Hardware quadrature input |
| D5 / `TIOA6` | Right encoder A from LVC245 B3 | Hardware quadrature input |
| D4 / `TIOB6` | Right encoder B from LVC245 B4 | Hardware quadrature input |
| D6 / `PWML7` | M1PWM | Set output LOW before configuring motor direction |
| D7 / `PWML6` | M2PWM | Set output LOW before configuring motor direction |
| D8, D9 | M1INA, M1INB | Set only while M1PWM is LOW |
| D10, D11 | M2INA, M2INB | Set only while M2PWM is LOW |
| D22, D23 | M1EN/DIAG, M2EN/DIAG | Inputs only; HIGH normal, LOW fault/disabled |
| A0, A1 | M1CS, M2CS through the `#2507` onboard 10 kΩ resistors | Analog inputs |
| Programming USB | Pi command/telemetry and Due power | No second powered USB host |
| 5 V, 3.3 V, GND | P8/P9 logic supplies and common reference | Outputs only in this design |

No default shield pin mapping or stock shield library pin assignment is
authoritative. Firmware must use this table.

Stage 2B Gate B5 temporarily connects D6 and then D7 to spare timer-capture
input D3 / `TIOA7` for same-controller PWM commissioning. D3 is disconnected
after that gate and has no installed baseline function.

## `74LVC245` Fixed Wiring

| IC pin | Connection |
|---|---|
| 1 `DIR` | Due 3.3 V, selecting A-to-B |
| 2 `A1` / 18 `B1` | Left encoder A / Due D2 |
| 3 `A2` / 17 `B2` | Left encoder B / Due D13 |
| 4 `A3` / 16 `B3` | Right encoder A / Due D5 |
| 5 `A4` / 15 `B4` | Right encoder B / Due D4 |
| 6-9 `A5-A8` | Logic ground |
| 10 `GND` | Common logic ground |
| 11-14 `B8-B5` | Leave unconnected |
| 19 `/OE` | Logic ground, permanently enabled |
| 20 `VCC` | Due 3.3 V |
| Across 20 and 10 | Owned `104`/0.1 uF ceramic capacitor, mounted at the IC |

## Ground and Safe-State Rules

1. Battery negative splits through the high-current distribution to the
   `#2507` power ground and DROK input ground. Motor return current must not
   use Due, Pi, encoder, or jumper-wire ground paths.
2. The DROK output ground establishes Pi ground; the Pi-to-Due USB cable then
   establishes Due logic ground. Join Due logic ground to `#2507` logic ground,
   translator ground, and both encoder grounds.
3. Before battery power, continuity-check that the selected ALITOVE ports form
   the intended common junction and verify whether DROK input/output grounds
   are common. Check polarity and tug-test every termination.
4. On Due reset, the board's PWM pull-downs hold both driver outputs
   high-impedance. Firmware must explicitly establish `PWM LOW`, then direction
   and input/fault configuration, before accepting a motion command.
5. On a stale command, both wheel targets ramp to zero and then coast. On
   either driver fault or a calibrated encoder stall, both channels coast and
   motion remains latched off until explicit reset.
6. The BNO055 is intentionally assigned to UART through the already-owned
   `#954` cable on one switched port of the owned bus-powered `#2998`. This
   avoids adding the sensor's I2C behavior to the Pi bus and matches the
   selected ROS 2 driver's 115200-baud path. Do not use the hub's external
   power jack and do not connect STEMMA I2C simultaneously.
7. Connect the Due to only one powered USB host. Connect the Pi by only one
   power method. These are wiring rules, not software preferences.

## Q10 Procurement Result

Q10 adds no unconditional immediate electronic or cable purchase:

- the `#2507` current-sense outputs connect directly to Due A0/A1 through the
  board's existing 10 kΩ series resistors; no external clamp diodes are
  required for the selected motors; and
- the camera bag already contains two cables. Use the supplied
  Standard-to-Mini cable with the narrow 22-pin Pi 5 end and wider 15-pin
  Camera Module 3 end.

Physically confirm that a data-capable USB-A-to-micro-B cable is already on
hand for the Due. Buy one only if it is missing. The `#2998` is owner-reported
as already owned even though BOM REV 02 omits it.

The battery-mating connector, battery-specific undervoltage solution, and
RPLidar A1 development kit remain deferred. BOM REV 02 records the selected
16 AWG red/black wire as owned.

## Evidence Sources

- [Pololu `#2507` product and electrical limits](https://www.pololu.com/product/2507)
- [Pololu Dual VNH5019 shield user's guide](https://www.pololu.com/docs/0J49/all)
- [ST VNH5019A-E datasheet](https://www.pololu.com/file/0J504/vnh5019a-e.pdf)
- [Pololu `#4753` motor and encoder specifications](https://www.pololu.com/product/4753)
- [Official Arduino Due specifications](https://store.arduino.cc/products/arduino-due)
- [Arduino Due core pin definitions](https://github.com/arduino/ArduinoCore-sam/blob/master/variants/arduino_due_x/variant.cpp)
- [Microchip SAM3X/SAM3A datasheet](https://ww1.microchip.com/downloads/en/devicedoc/atmel-11057-32-bit-cortex-m3-microcontroller-sam3x-sam3a_datasheet.pdf)
- [TI SN74LVC245A datasheet](https://www.ti.com/lit/ds/symlink/sn74lvc245a.pdf)
- [Raspberry Pi 5 power documentation](https://www.raspberrypi.com/documentation/hardware/raspberrypi/power/raspberry-pi-5.html)
- [Raspberry Pi camera connector documentation](https://www.raspberrypi.com/documentation/accessories/camera.html)
- [Adafruit BNO055 pinouts](https://learn.adafruit.com/adafruit-bno055-absolute-orientation-sensor/pinouts)
- [Adafruit `#954` USB-to-TTL cable](https://www.adafruit.com/product/954)
- [Adafruit `#2998` USB Mini Hub with Power Switch](https://www.adafruit.com/product/2998)
- [Raspberry Pi USB current and single-TT hub guidance](https://www.raspberrypi.com/documentation/computers/raspberry-pi.html#universal-serial-bus-usb)
- [ROS 2 BNO055 UART wiring and parameters](https://github.com/flynneva/bno055)
- [SLAMTEC RPLidar A1 specifications](https://www.slamtec.com/en/lidar/a1spec)
- [SLAMTEC RPLidar A1M8 datasheet](https://wiki.slamtec.com/download/attachments/83066883/LD108_SLAMTEC_rplidar_datasheet_A1M8_v3.0_en.pdf?api=v2)

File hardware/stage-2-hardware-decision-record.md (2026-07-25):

# Stage 2 Hardware Decision Record

**Status:** Q3-Q11 complete; Stage 2A is complete. Pololu Dual VNH5019 shield
`#2507` is selected and received, its Phase 1 motor-control/protection policy
is defined, and the encoder, Due-power, and Raspberry Pi power paths are
selected below. Physical identity and the bench-test equipment were
owner-accepted at B1 and B2 on 2026-07-25. Assembly, commissioning values, and
downstream Stage 2B acceptance remain pending.

**Last reviewed:** 2026-07-25

This is the concise record of the resolved Stage 2A hardware choices.
[The phase plan](../docs/phases.md) defines their Stage 2B execution order. The
[component selection audit](component-selection-audit.md) preserves the longer
history and calculations behind these findings.

## Verified Constraints

- The robot has two Pololu `#4753` 12 V, 50:1 encoder gearmotors and therefore
  needs two independently controlled H-bridges.
- Each motor is specified at 0.2 A no load, 0.66 A at maximum efficiency, and
  5.5 A theoretical stall at 12 V. Pololu's general guidance to keep continuous
  load near or below 25% of stall corresponds to about 1.38 A per motor; stall
  is not a normal operating point.
- The owned Pololu `#2991` is one 17 A motor channel, not a dual driver. Its
  headers were supplied loose; user soldering is now acceptable, but this does
  not make it a sensible two-channel solution for the present motors.
- The Arduino Due uses 3.3 V I/O and its inputs are not 5 V tolerant.
- The motor encoders require at least 3.5 V. Supplying them at 5 V therefore
  requires a verified four-channel 5 V-to-3.3 V interface before the Due.
- The project uses commercial off-the-shelf products assembled by the user.
  Soldering supplied headers and ordinary wiring is acceptable. Hired custom or
  professional assembly is outside the hobbyist scope. Crimping is not assumed.
- Phase 2 self-balancing suitability cannot be proven from a static torque
  calculation. Q2 uses a preliminary wheeled-inverted-pendulum screen only to
  establish whether the owned motors and wheels remain plausible reuse.

## Q2 Analysis: Phase 2 Reuse Boundary

**Status:** Complete. Nathan approved the narrow reuse boundary below.

The physical-property register, equations, reproducible calculation, scenario
results, assumptions, and limitations are recorded in
the [Phase 2 preliminary dynamic model](phase-2-dynamic-model.md).

The planar model includes both wheel traction (`T/r`) and the motor reaction
torque on the body (`-T`). Across the documented 1.0-2.0 kg body-mass,
0.08-0.20 m center-of-mass-height, and body-inertia scenarios, an idealized
10-degree/0.30-second recovery screens at:

- 0.027-0.094 N·m output torque per motor;
- approximately 0.15-0.44 A per motor using two fits that bracket conflicting
  Pololu no-load-current data;
- 65-133 rpm wheel demand, compared with approximately 150-157 rpm available
  in the 9.6 V reduced-voltage sensitivity case; and
- 52-115 ms open-loop e-fold time.

These assumed scenarios are a plausibility screen, not final Phase 2 properties
or requirements.

### Approved reuse boundary

- **Required reuse while plausible:** both owned Pololu `#4753` motors,
  including their integrated encoders, and the owned 80 mm wheels with 6 mm
  hubs. The screen found no reason to replace them, so no new motors or wheels
  are planned. Replacement is reconsidered only if later physical Phase 2
  evidence demonstrates infeasibility.
- **Outside Q2:** every other Phase 1 component, Phase 2 physical property,
  chassis decision, controller choice, sensor choice, and power decision.
  Select and validate current hardware for Phase 1 without requiring knowledge
  of the unbuilt Phase 2 robot.
- **No Q3 dependency:** Q2 did not select or size a motor driver. Q3 was
  completed separately afterward.

## Q3 Analysis: Two-Channel Motor Drive

**Status:** Complete. Nathan approved Pololu `#2507` on 2026-07-23 with the
implementation conditions recorded below.

### Scope and selection standard

Q3 selects a two-channel driver for the known Phase 1 robot: two `#4753`
motors, an Arduino Due, and a 3S battery architecture that can reach 12.6 V.
The driver should also remain credible for a later Phase 2 that continues to use
the same motors and wheels. This does not assume or decide any other Phase 2
property.

Useful future-readiness means:

- enough electrical and thermal margin that the driver is not the first
  component forced to its limit;
- a Due-safe interface and a command path credible for a faster future control
  loop;
- observable current, voltage, and fault state where practical;
- explicit system-level treatment of current limiting and command loss when
  those functions are not independently provided by the driver; and
- an off-the-shelf installation that does not require custom fabrication or an
  unresolved high-current connector.

Raw current rating by itself is not useful future-readiness. The fixed motors
still draw only what their voltage, winding resistance, speed, and load demand.
An oversized driver is acceptable when its extra capability comes with usable
protection and diagnostics rather than merely increasing the available fault
current.

### Current product comparison

Prices below are manufacturer one-piece prices reviewed on 2026-07-22 and
exclude tax and shipping.

| Exact candidate | Relevant interface and capability | Safeguards, assembly, and cost | Q3 result |
|---|---|---|---|
| Pololu Motoron M2S18v18 with connectors soldered `#5036` | Dual 18 A channels, 6.5-30 V motor supply, 3.0-5.5 V logic, I2C up to 400 kHz, selectable 1-80 kHz internal PWM. A `Set all speeds` command changes both channels together and its `now` mode applies the new output immediately. | Configurable hardware current limit, current and VIN measurement, CRC, configurable error response, command timeout, and motor-supply reverse protection. Factory-soldered stack headers and three motor/power terminal blocks; **$69.95**. It does not have meaningful over-temperature protection. | **Not selected.** Its current limit, timeout, and telemetry are useful, but they do not justify exceeding the under-$50 board budget for this project. |
| **Pololu Dual VNH5019 shield `#2507`** | Direct PWM up to 20 kHz, 12 A continuous/30 A peak per channel, 3.3 V-compatible inputs, and approximately 140 mV/A current sense. Pololu has tested the shield and library with the Due and identifies VNH5019 drivers as a good match for the owned `#4753` motors. | Reverse protection, thermal shutdown, over/under-voltage shutdown, and output-short protection, but no motor-matched configurable current limit or independent command timeout. Included headers and terminals require soldering; **$39.95**. | **Selected.** It meets Phase 1 actuation needs, stays under the board budget, and preserves direct control and adequate margin for the same motors in a plausible later Phase 2. The five implementation conditions below are mandatory. |
| Pololu Dual TB9051FTG shield `#2520` | Direct 20 kHz PWM, 2.6 A continuous/5 A peak per channel, about 500 mV/A current sense, and IOREF-based 3.3 V logic. | Fixed current chopping is typically about 6.5 A, with thermal current reduction, over-temperature/over-current diagnostics, and reverse protection. Included headers and terminals require soldering; **$31.95**. Its current-monitor voltage approaches the Due's 3.3 V ADC limit near fault current. | **Good Phase 1 value, not the best carry-forward choice.** Less transient and thermal margin, and the current-sense interface needs more care. |
| Pololu Dual MC33926 shield `#2503` | Direct 20 kHz PWM, 3 A continuous/5 A peak per channel, 3.3 V logic, and approximately 525 mV/A current sense. | Internal peak limiting around 6.5 A ±1.5 A, thermal and output-short protection, and motor-supply reverse protection. Included headers and terminals require soldering; **$44.95**. Product status is active rather than active-and-preferred. | **Superseded in this comparison.** It costs more than the TB9051 and VNH5019 alternatives without winning either the protection/fit or future-headroom comparison. |
| Pololu Dual G2 18v18 shield `#2515` | Direct PWM up to 100 kHz, 18 A continuous per channel, 3.3 V logic, and approximately 20 mV/A current sense. | Reverse, undervoltage, and short-circuit protection. The default current limit is approximately 50 A; it can be lowered with resistors but is less accurate at low settings. There is no dependable MOSFET over-temperature shutdown. Included connectors require soldering; **$74.95**. | **Not recommended.** Its raw output capacity is not accompanied by a motor-matched default limit, strong low-current telemetry, or the Motoron's independent timeout. |
| A second Pololu G2 18v17 `#2991` | Two separate direct-PWM 17 A boards would be required. The second board alone is **$44.95**; the first is already owned. | Each board has a roughly 40 A default current limit, approximately 20 mV/A current sense, and no dependable MOSFET over-temperature shutdown or command timeout. | **Not selected.** It is electrically usable, but the `#2507` provides two channels, stronger thermal protection, and better low-current feedback for less new expenditure. Reserve the owned `#2991` for later one-channel use. |
| Cytron MDD10A Rev 2.0 | Direct 20 kHz PWM, 10 A continuous/30 A peak per channel, 3.3 V inputs, and factory-soldered power terminals; **$25.90**. | No motor-supply reverse-polarity protection, current feedback, configurable current limit, or independent command timeout. Its supplied logic plug uses loose crimp terminals, while crimping is not assumed. | **Budget option only, not recommended.** It removes the diagnostics and fail-safe features that justify deliberate Phase 1 overengineering. |

Two DRV8871-class boards and Raspberry Pi expansion boards remain excluded:
the former give up transient margin without a compelling installed-cost
advantage, and the latter put the wrong controller in the motor-command path.

### Approved exact implementation

Select **one Pololu Dual VNH5019 Motor Driver Shield for Arduino, item
`#2507`**. Although sold as a shield, install it as a separately mounted
general-purpose motor-driver board. This avoids relying on the shield's 5 V
logic supply for the enable/fault pull-ups and permits deliberate Due pin
allocation for motor control and the two quadrature encoders.

### Connection and assembly boundary

The surface-mount electronics arrive assembled, but Pololu does not offer a
factory-soldered `#2507`. For the selected general-purpose configuration,
Nathan will solder the three included 2-pin motor/power terminal blocks and a
13-pin section of the included logic header: 19 through-hole joints. Do not
install the Arduino stackable headers or the optional `ARDVIN=VOUT` power
jumper.

- Supply driver `VDD` from the Due's 3.3 V rail and join driver and Due ground.
  Connect each channel's PWM, two direction inputs, enable/fault output, and
  current-sense output through the logic header. The exact Due pins are fixed
  in the [Q10 interface matrix](power-signal-interface-matrix.md).
- Connect the two motor-power leads from one `#4753` to `M1A/M1B` and the other
  motor to `M2A/M2B`. Establish final channel names and polarity during the
  unloaded direction test.
- Connect only the future protected motor branch to the driver's large
  `VIN/GND` terminal. Do not use the driver to power the Due or Pi. Q6-Q8
  define their supplies and protection policy; Q9 owns the physical
  distribution design.
- Mount the board using its two #4 mounting holes and provide strain relief for
  the motor and power leads. Do not use the owned `#2991` in parallel or as a
  third channel.

### Mandatory implementation conditions

1. **Separate 3.3 V logic installation:** use the `#2507` as the separately
   mounted general-purpose board described above, with `VDD` connected to the
   Due's 3.3 V rail. This avoids ambiguity about 5 V fault-line pull-ups and
   allows the motor and encoder pins to be allocated deliberately.
2. **Use the board-protected current-sense outputs:** connect `M1CS` and
   `M2CS` directly to Due A0/A1 through the `#2507` logic header. The board
   already places 10 kΩ in series with each output, which Pololu considers
   generally safe for 3.3 V MCU inputs. At the motors' 5.5 A theoretical stall
   current, the signal is only about 0.77 V; reaching 3.3 V would require about
   23.6 A on one channel, far outside these motors' electrical envelope. No
   external clamp diode is required. Reconsider this only if the motor/current
   envelope changes.
3. **Resolve Due PWM and current-sense sampling:** the stock Pololu library
   does not guarantee 20 kHz PWM on the Due, and Pololu warns that its current
   readings are unreliable below about 5 kHz without filtering. Q4 selects
   20 kHz Due hardware PWM, so the low-frequency capacitor is not required;
   Q10 assigns D6/D7 for hardware PWM and A0/A1 for current sense; Stage 2B
   must verify PWM and current readings.
4. **Provide system-level motor protection:** the `#2507` has no configurable
   motor-matched current limit or independent command timeout. Q4 defines the
   firmware command-loss, driver-fault, and encoder-stall responses below,
   while Q8 provides the selected system fuse. These functions may not
   be assumed from the board's 12 A rating or its short-circuit protection.
5. **Keep thin owned wire out of motor power:** JST-SH, STEMMA QT, and Dupont
   leads remain signal-only. The final battery and motor-power harness remains
   a Q9 decision based on limits, the Q8 fuse value, run lengths, and terminals.

Q3 chooses the hardware and connection form only. The Q4 resolution below
defines the associated Phase 1 operating policy.

## Q4 Resolution: Motor Protection and Control Policy

**Status:** Complete as a Stage 2A design decision. Stage 2B still owns
measurement, calibration, and bench acceptance.

### Scope and reference comparison

Phase 1 operates indoors on smooth, substantially level surfaces. It does not
have a steep-slope holding requirement. Q4 does not impose a Phase 2 balancing
policy.

Comparable robots support a local stale-command stop but do not share a
universal electrical-braking sequence. TurtleBot3 sends zero motor velocity
after a 500 ms control timeout; Linorobot2 uses a 200 ms command timeout and
makes short braking optional; Pololu's Balboa balancing example continuously
controls ordinary encoder-equipped DC gearmotors and its zero command brakes
because of that platform's driver topology. None establishes a timed
brake-then-coast requirement for this Phase 1 robot.

- [TurtleBot3 OpenCR timeout configuration](https://github.com/ROBOTIS-GIT/OpenCR/blob/master/arduino/opencr_arduino/opencr/libraries/turtlebot3/examples/turtlebot3_burger/turtlebot3_core/turtlebot3_core_confi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)
- [Linorobot2 firmware and configuration](https://github.com/linorobot/linorobot2_hardware/tree/jazzy/firmware)
- [Pololu Balboa balancing example](https://github.com/pololu/balboa-32u4-arduino-library/tree/master/examples/Balancer)

### Selected Phase 1 policy

| Concern | Decision | Stage 2B evidence still required |
|---|---|---|
| Motor voltage and PWM | Accept a 12.6 V fully charged 3S source and initially cap motor duty at 95%, corresponding to approximately 12.0 V maximum average motor voltage. Generate 20 kHz PWM using Due hardware rather than assuming the stock Pololu library provides it. | Measure frequency, duty, polarity, and motor-terminal behavior first with one unloaded channel. |
| Continuous and transient current | Use approximately 1.38 A per motor, 25% of the 5.5 A theoretical stall current, as the continuous design target. Startup and acceleration may briefly exceed it while encoder progress is present. The 5.5 A stall value is not an allowed operating point. Do not invent a current-versus-time shutdown curve from unsupported data; use current sensing for measurement and diagnosis while encoder-stall logic provides the primary motor-protection response. | Record unloaded, startup, maneuvering, and representative loaded currents. Normal loaded duty must remain near or below the continuous target. |
| Normal commanded stop | Apply a bounded controller deceleration to a zero wheel-speed target, then command the VNH5019 coast state near standstill. Do not apply a fixed active-braking pulse. | Tune the deceleration limit and near-zero transition to avoid wheel slip, excessive stopping distance, or oscillation. |
| Startup, reset, and command loss | Initialize both channels in coast before accepting motion. A 500 ms Due-side serial-command watchdog sets both wheel targets to zero and proceeds to coast; a later valid command may restore motion without a manual reset. Never resume a pre-reset or stale command. | Verify power-up, Due reset, firmware upload, serial disconnect, and reconnect behavior with wheels clear of the surface first. |
| Driver fault | A fault indication from either channel commands both channels to coast and latches motion off until an explicit reset after the cause is removed. Stopping both avoids an unintended powered pivot. | Inject or safely simulate the readable fault states without intentionally shorting the driver. |
| Encoder stall | After an empirically determined startup grace period, a meaningful motion command with inadequate encoder progress commands both channels to coast and latches a stall fault. Current is corroborating telemetry, not the sole trigger. | Determine the arming command, minimum progress, grace period, and detection interval from unloaded and representative loaded tests. |
| Thermal acceptance | Do not assign unsupported fixed motor-case or driver-board temperature limits. A representative loaded duty cycle passes only if current remains consistent with the continuous design target, temperatures approach a stable trend, and no driver fault, controller reset, or progressive performance loss occurs. | Record ambient, motor and driver temperature behavior, current, voltage, run duration, and faults; reject a configuration whose temperatures continue rising without a credible plateau. |
| Current-sense interface | At 20 kHz, do not add the capacitor Pololu recommends only for PWM below 5 kHz. Connect the shield's 10 kΩ-isolated current-sense outputs directly to Due A0/A1 without external clamp parts; the selected motors produce only about 0.77 V at theoretical stall. Firmware may average calibrated samples. | Q10 assigns A0/A1 for current sense and D6/D7 for PWM. Stage 2B verifies ADC level, zero offset, scaling, noise, and useful readings under PWM. |

The unmeasured tuning values above are commissioning parameters rather than
unresolved architecture choices. Keeping them in Stage 2B preserves the
distinction between defining a testable policy and claiming evidence that can
exist only after the hardware arrives.

## Q5 Resolution: Encoder Interface

**Status:** Complete as a Stage 2A design decision. Nathan selected the
Adafruit `74LVC245` product `#735` and Adafruit 20-pin socket `#2204` on
2026-07-23. They have arrived and were owner-accepted at B1; assembly and
powered bench acceptance remain pending.

### Why an interface is required

Each `#4753` encoder requires 3.5-20 V and produces two digital outputs that
swing from ground to its supply voltage. The Due's I/O limit is 3.3 V, so the
encoder cannot be powered within specification and connected directly to the
Due. Power both encoders from a regulated **5 V encoder rail** and translate
their four outputs to 3.3 V before they reach the Due.

The selected `74LVC245` is a fixed-direction digital buffer/level translator,
not an encoder decoder. Operated from the Due's 3.3 V rail, it accepts inputs
up to 5.5 V and produces 3.3 V logic outputs. Its specified propagation delay
of at most 6.3 ns at 3.3 V is negligible relative to the encoder signals:
at the motor's 200 rpm no-load output speed and exact 50:1 ratio, each encoder
channel is approximately 2.67 kHz and full quadrature decoding produces about
10.67 thousand count events per second per motor. Count integrity remains a
Stage 2B measurement rather than an assumed result.

### Selected implementation

- Use one Adafruit `74LVC245` 8-bit logic level shifter, product `#735`, in one
  Adafruit 20-pin 0.3-inch IC socket, product `#2204`. The socket must be
  soldered to a suitable prototyping board; the IC then plugs into the socket.
  The owned Mega Prototype Shield V3 is the preferred carrier if visual and
  continuity inspection confirms its 0.1-inch prototyping area and rail
  routing. Otherwise use a small solderable perfboard.
- Connect `74LVC245` pin 20 (`VCC`) to Due 3.3 V and pin 10 to common logic
  ground. Connect pin 1 (`DIR`) to 3.3 V and active-low pin 19 (`/OE`) to
  ground for permanent A-to-B operation.
- Install one 0.1 uF ceramic bypass capacitor directly between pins 20 and 10.
  Tie unused A-side inputs A5-A8, pins 6-9, to ground; leave unused B-side
  outputs B5-B8, pins 11-14, unconnected.
- Do not substitute a `74HC245`, `74HCT245`, `TXB0108`, or an unspecified
  auto-direction translator. The approved retail item is specifically
  Adafruit `#735`, whose `74LVC245` behavior matches this fixed 5 V-to-3.3 V
  application.

### Encoder and Due mapping

| Motor signal | Translator path | Due hardware input |
|---|---|---|
| Left yellow, encoder A | pin 2 `A1` to pin 18 `B1` | D2, `TIOA0` |
| Left white, encoder B | pin 3 `A2` to pin 17 `B2` | D13, `TIOB0` |
| Right yellow, encoder A | pin 4 `A3` to pin 16 `B3` | D5, `TIOA6` |
| Right white, encoder B | pin 5 `A4` to pin 15 `B4` | D4, `TIOB6` |

D2/D13 form one SAM3X Timer Counter quadrature-decoder pair and D5/D4 form a
second. Direction sign is established during the unloaded rotation test rather
than inferred from chassis orientation. Because D2 and D4 are default `#2507`
shield-control pins, the separately mounted driver's control lines do not use
the default shield mapping; Q10 assigns D6-D11, D22-D23, and A0-A1.

For each motor harness, red and black remain motor-power leads and go to that
channel's `#2507` output terminal. Green joins common logic ground, blue joins
the regulated 5 V encoder rail, and yellow/white enter the translator. The
six-pin motor harness does not plug into either the IC or the motor driver as a
unit. Q9 and the Q10 matrix define the secured connector implementation; Stage
2B still inspects the owned prototype shield and harnesses before power.

Q6 selects the Due's 5 V output as the encoder rail during both bench and mobile
operation. The Due is powered through its Programming USB port, so do not feed
an external supply into the Due 5 V pin. The translator itself always uses Due
3.3 V, and the Due, translator, both encoders, and `#2507` logic must share
ground. Never power an encoder from the 12 V motor rail while it is connected
to the translator, whose inputs are limited to 5.5 V.

### Stage 2B acceptance

Before motor power is applied, verify socket orientation, continuity, absence
of 5 V at every Due input, and correct 5 V/3.3 V logic levels while each wheel
is turned by hand. Then test one unloaded motor and both unloaded motors through
their full allowed speed range, compare observed direction and counts with the
expected 3200 counts per output-shaft revolution, and reject any circuit that
shows missed, extra, or direction-reversed counts that cannot be explained by
the defined polarity convention.

## Q6 Resolution: Arduino Due Power

**Status:** Complete as a Stage 2A design decision. Nathan approved the
USB-powered implementation below on 2026-07-23. No additional Due power
converter is selected or required; cable and bench acceptance remain pending.

### Selected bench and mobile method

Use the Due as a bus-powered Raspberry Pi USB peripheral:

- **Bench:** power the Due through its Programming USB port from the Raspberry
  Pi or, for isolated Due testing, from one development computer. Keep the motor
  driver's current-limited bench supply separate while joining its ground to
  Due ground before control signals are connected.
- **Mobile:** connect one Raspberry Pi USB-A host port to the Due's Programming
  USB port with a data-capable USB cable. This one cable supplies the Due and
  carries its serial command/telemetry connection.
- Use the Due's 5 V output for the two encoders, whose maximum combined draw is
  20 mA. Use the Due's 3.3 V output for the `74LVC245` and the separately
  mounted `#2507` logic `VDD`. Join Due ground to both encoder grounds, the
  translator, and the `#2507` ground. Q9 owns the physical ground distribution
  so motor return current does not travel through logic wiring.

No direct connection from the motor battery or owned DROK converter to the Due
is part of this design. In particular:

- do not feed the historical 5.1 V rail into `VIN`; the specified external
  supply range is 7-12 V;
- do not apply raw 3S battery voltage to `VIN` or the barrel jack; a fully
  charged 3S battery reaches 12.6 V, above the recommended range and near the
  high-dissipation end of the Due's linear-regulator path; and
- do not use the Due's 5 V or 3.3 V pins as power inputs. Arduino advises
  against this because it bypasses onboard regulation and protection.

A separate regulated 7.5 V barrel-jack supply would be electrically valid but
is intentionally rejected as redundant for Phase 1. If a later Phase 2
establishes a measured need for power independence from the Pi, it can add a
separate logic supply without changing the Q5 encoder interface.

### USB coexistence and current boundary

- Only one USB host may connect to and power the Due at a time. Normally that
  host is the Pi. Before connecting a laptop directly, disconnect the Pi-to-Due
  USB cable; do not use the Programming and Native USB ports from two powered
  hosts simultaneously.
- Program and communicate with the Due from the Pi over the same Programming
  USB cable when practical. A Pi reboot does not create a stale-command
  exception: Q4's 500 ms watchdog and reset-safe coast behavior still apply.
- The Due's USB input has a 500 mA resettable polyfuse. Treat 500 mA as the
  conservative unmeasured ceiling for the complete Due/encoder/translator
  branch until Stage 2B records its actual consumption.
- Raspberry Pi 5 limits total downstream USB peripheral current to 600 mA with
  a 3 A supply and permits 1.6 A when it recognizes a 5 A supply such as the
  official 27 W unit. The official unit therefore supports bench work. Q7 must
  account for the measured Due branch and all other USB peripherals; the Q7
  mobile path now does so, subject to Stage 2B load validation.

### Stage 2B acceptance

With motor power initially disconnected, verify the Due enumerates on the Pi,
uploads firmware, maintains serial communication, and presents acceptable 5 V
and 3.3 V rails with both encoders and the translator connected. Record the
branch current if suitable measurement equipment is available. Then verify
Due/Pi startup order, Pi reboot, USB disconnect/reconnect, Due reset, firmware
upload, and motor startup do not cause unintended drive, repeated controller
resets, USB over-current, or corrupted encoder counts. Perform direct-laptop
testing only after disconnecting the Pi USB host.

## Q7 Resolution: Raspberry Pi Power

**Status:** Complete as a Stage 2A design decision. Nathan approved the owned
DROK mobile-power path below on 2026-07-23. No additional Raspberry Pi power
board is selected; physical acceptance remains in Stage 2B.

### Selected bench and mobile methods

- **Bench/tethered:** power the Raspberry Pi 5 directly from the owned official
  27 W USB-C supply. The Pi then powers and communicates with the Due through
  the Q6 USB connection.
- **Mobile:** use a protected 3S battery distribution branch, defined in Q8, to
  feed the owned DROK adjustable buck converter. Set its output to **5.10 V**
  before connecting the Pi, then feed the Pi through its 5 V and ground header
  pins using short, suitably heavy conductors. The Pi continues to power and
  communicate with the Due over USB.
- Do not use the DROK for the motor branch. Do not connect the official USB-C
  supply while the Pi is powered through its header.

Direct header power avoids USB-C Power Delivery negotiation. After the entire
mobile path has demonstrated a sustained 5 A capability, configure the Pi
bootloader with `PSU_MAX_CURRENT=5000` so the Pi permits the higher USB
peripheral-current budget. Do not use that setting as a substitute for proving
the converter, wiring, connections, and battery branch.

The Pi 5's unusual aspect is its optional 5 V/5 A mode: a generic high-wattage
USB-C source may provide its headline power only at higher voltages and leave
the Pi in the lower USB-current mode. Hobbyist mobile robots commonly avoid
that ambiguity either with a capable buck converter connected to the 5 V
header or with a Pi-specific USB-C PD board. The latter adds connector and
automatic-negotiation convenience, but is not necessary if the owned DROK path
passes validation.

### Implementation and acceptance boundary

Before the DROK ever powers the Pi:

1. Identify its exact variant and physical markings, inspect the board, and
   confirm its documented input range and credible sustained-output capability.
2. Set and independently measure 5.10 V with the Pi disconnected. Repeat power
   cycles and reject the unit if its output overshoots or does not return to a
   safe, stable value.
3. Validate regulation and temperature progressively, measuring voltage at the
   end of the actual Pi power connection rather than only at the converter.
4. Exercise Pi boot, CPU, NVMe, camera, Due, and later LiDAR loads, then repeat
   while the motor branch starts and runs. Reject a path that produces Pi
   undervoltage warnings, USB over-current, resets, unsafe temperature, or
   unstable output.
5. Secure and cover the DROK adjustment controls after setting them. Never
   adjust the converter with the Pi connected.
6. Use `PSU_MAX_CURRENT=5000` only after the complete path passes the 5 A
   validation, and verify that the Pi reports the high-current USB mode.

The available information does not establish an independent fail-high output
over-voltage cutoff on the owned DROK. Adjustment control, pre-connection
measurement, repeated power cycling, and physical securing address the
credible setup risks without adding another board. If exact-unit inspection or
testing shows inadequate regulation, thermal performance, sustained current,
or unsafe startup behavior, Q7 must be reopened and a dedicated protected
5 V/5 A supply selected.

Q7 selects the conversion topology only. Q8 supplies the minimal upstream
protection policy below. Q9 owns ground distribution, branch wiring, and
physical parts; Q10 records the completed interface matrix.

## Q8 Resolution: Power Protection Policy

**Status:** Complete. Nathan clarified on 2026-07-23 that cables, wire gauges,
terminals, connectors, splices, and physical distribution hardware belong to
Q9 rather than Q8.

The Q8 protection decisions are:

- install one 10 A standard ATO/ATC fuse in the battery-positive feed, as close
  to the battery as the Q9 harness implementation reasonably permits;
- place both the motor-driver and DROK branches downstream of that fuse; and
- do not add branch fuses, a fused distribution block, or another protection
  board merely to duplicate the main fuse;
- use the keyed battery connector selected in Q9 as the normal manual power
  disconnect rather than adding a separate emergency-stop or high-current
  switch;
- rely on that keyed connector and the selected driver's built-in protection
  rather than add another reverse-polarity board; and
- use the `#2507` as supplied without another local capacitor unless Stage 2B
  measurements reveal an actual supply-transient problem.

The owned 1 A toggle is not approved to interrupt battery current. A
battery-specific undervoltage protection or monitoring method must be selected
with the deferred 3S battery before Stage 4 mobile operation; it does not
justify adding another unspecified board to the Stage 2 Q8 design.

## Q9 Resolution: Physical Power Distribution and Owned-BOM Gap Check

**Status:** Complete by Nathan's direction on 2026-07-23. This closes the
physical-part selection; it does not waive the staged electrical acceptance
tests required before mobile use.

Use the following implementation:

- use 16 AWG stranded copper for the battery trunk and battery-side branches;
- place the selected 14 AWG inline ATO/ATC holder and Q8 10 A fuse near battery
  positive;
- use the eventual battery's keyed/polarized mating connector, rated for at
  least the 10 A fused path, as the normal manual disconnect; its exact SKU is
  intentionally selected with the still-deferred battery;
- use the owned ALITOVE splice connectors for the fused distribution junction
  where their actual internal topology permits it. Nathan reports markings up
  to 10 AWG and 32 A. Continuity-check whether the ports form a common junction
  or independent pairs before wiring, then individually tug-test every wire;
- land the motor factory leads and battery feed directly in the supplied
  `#2507` terminal blocks. Do not extend a motor or battery path with JST-SH or
  Dupont jumper wire;
- feed the Pi from the validated DROK output using two equal-length, short
  Elegoo/Dupont leads in parallel to the two Pi 5 V pins and two equal-length,
  short Elegoo/Dupont leads to separate Pi ground pins. Keep each lead at or
  below approximately 12 inches; and
- use the owned JST/STEMMA cables or Elegoo jumpers for the remaining
  low-current power and signal wiring downstream of the Pi, including the
  controller, level translator, driver logic, encoders, and sensors, subject to
  the Q10 pin/interface matrix. The Pi-to-Due connection remains the Q6
  data-capable USB cable. JST/STEMMA cables are used only where a matching
  socket exists; none is forced into the current baseline.

The Elegoo lead gauge and contact rating remain undocumented. Nathan has
accepted their use for the Pi-power connection with caution. Stage 2B must
therefore check polarity and continuity before connection, measure the DROK
both unloaded and at the Pi header under load, monitor the four jumpers and
contacts for heating, check for Pi undervoltage/reset indications, and reject
the arrangement if it cannot sustain the Q7 load test. Failing this acceptance
test requires replacement with rated 22 AWG pre-terminated leads; it does not
reopen the Q9 topology decision.

Owned-item disposition:

- the ALITOVE splices are the selected distribution/splice method after the
  topology and mechanical checks above;
- the white screw-terminal strips remain optional secured bench fixtures, not
  required mobile distribution hardware;
- the 1 A toggle is available only for a future low-current enable/control
  function and is not in the selected power path;
- the INA219 is optional for controlled low-current measurements and is not
  the main battery/motor current sensor;
- the DROK is assigned exclusively to the Q7 mobile Pi branch; and
- the owned JST/STEMMA and Elegoo leads cover downstream low-current
  power/signals. BOM REV 02 records the selected 16 AWG red/black copper as
  owned; the battery-mating connector remains battery-selection-dependent;
  and
- the owner-reported Adafruit `#2998` is used bus-powered from one black Pi USB
  2.0 port for only the `#954`/BNO055 branch. Its external-power jack remains
  unused; the Due and future RPLidar stay on direct Pi ports.

## Q10 Resolution: Power and Signal Interface Matrix

**Status:** Complete as a Stage 2A design definition on 2026-07-23. Physical
continuity, voltage, timing, current, temperature, reset, and fault behavior
remain Stage 2B evidence.

The authoritative
[Phase 1 power and signal interface matrix](power-signal-interface-matrix.md)
records every installed or planned baseline interface, including direction,
voltage/current limits, thresholds, channel count, Due pins, connector/wire,
protection, shutdown state, and controlling device.

Key allocations are:

- Due D6/D7 for 20 kHz M1/M2 PWM; D8-D11 for direction; D22/D23 as
  input-only driver fault lines; and A0/A1 for current sense;
- direct `#2507` current-sense connections to A0/A1 through the board's
  existing 10 kΩ series resistors, with no external clamp parts;
- the existing Q5 D2/D13 and D5/D4 encoder pairs through the `74LVC245`;
- the owned Adafruit `#954` USB-to-TTL cable for BNO055 UART at 115200 baud;
- the owner-reported owned Adafruit `#2998` as a bus-powered switched hub
  between a Pi USB 2.0 port and the low-current `#954`/BNO055 branch;
- the Pi's CAM/DISP connector and a 22-to-15-pin Standard-to-Mini cable for
  Camera Module 3; and
- a direct Pi USB connection through the future RPLidar A1 development-kit
  adapter, included in the validated Pi USB/power budget.

The matrix explicitly excludes optional parts that have no baseline function.
Q10 adds no unconditional procurement item: external current-sense clamps are
unnecessary for these motors, the camera bag contains the required Pi 5
Standard-to-Mini cable, and the `#2998` is already owned. The
USB-A-to-micro-B data cable for the Due must be physically confirmed and
purchased only if absent.

## Q11 Resolution: Procurement Record

**Status:** Complete by Nathan's direction on 2026-07-23.

[BOM REV 02](Bill%20of%20Materials%20-%20Sheet%20REV%2002.pdf) is the accepted
current procurement snapshot. The previous PDF remains recoverable in
`hardware/_archive`. No further BOM cleanup is required to close Stage 2A;
physical validation remains governed by Stage 2B rather than the BOM.

## Q1 Resolution: Assembly Boundary and Owned Wiring

Q1 is closed. The inventory classification below establishes what is usable
now and includes the later Q9 assignments.

| Owned item | Documented rating or construction | Accepted use and termination |
|---|---|---|
| Two `#4753` factory motor/encoder harnesses | Six color-coded 20 cm leads terminating in one 1x6 female 2.54 mm header. The encoder draws at most 10 mA; Pololu does not publish the individual lead gauges. | The original harness is usable. Keep the four encoder conductors as low-current signal/power leads. The red/black motor leads may be removed from the housing or cut, stripped, and landed in the selected driver's rated terminal or soldered to an appropriate off-the-shelf connector. Do not extend the motor pair with Dupont or JST-SH wire. |
| 3x Pololu `#5534` five-pin female-female cables | 28 AWG, 1 A, 50 V, 16 cm, JST-SH-type 1 mm connectors. | Signal and low-current sensor power only. Plug into matching JST-SH headers; do not use for motors, battery, Pi power, or a shared power bus. |
| 3x Pololu `#5530` five-pin single-ended cables | 28 AWG, 1 A, 50 V, 12 cm, female JST-SH-type connector to bare leads. | Signal and low-current sensor power only. The bare end may be soldered or temporarily clamped in a suitable low-current terminal after pinout verification. |
| 3x 100 mm and 2x 200 mm Adafruit STEMMA QT cables | Four-conductor JST-SH 1 mm I2C cables; Adafruit specifies sensor power, ground, SDA, and SCL use but does not publish a cable current rating. | Use only for intended STEMMA QT/Qwiic sensor interfaces such as the BNO055 and INA219. Not general power wire. |
| Assorted Elegoo/Dupont jumper leads | Gauge and contact-current rating are not documented in the BOM. | Q9 accepts two short parallel positive and two short parallel ground leads for DROK-to-Pi power, subject to explicit Stage 2B voltage-drop, heating, and full-load rejection criteria. Also accepted for low-current power and signals downstream of the Pi. Never use them for a motor or battery-side path. |
| ALITOVE 3-in/3-out lever splice connectors | Nathan reports physical markings up to 10 AWG and 32 A; a traceable manufacturer datasheet is not recorded. | Q9 accepts them on the 10 A fused distribution path after continuity confirms the required internal topology and every termination passes an individual tug test. Reject any connection that loosens or heats during Stage 2B loading. |
| Weewooday 12-position screw-terminal strips | Listing claims 10 A, 380 V, and wire up to 2.5 mm²; no traceable manufacturer datasheet or vibration qualification is available. | Acceptable as a secured, inspected bench terminal below its rating with a current-limited/fused source. Not accepted as the final mobile battery bus. Use properly stripped bare wire under the clamp and perform a tug test; do not tin stranded wire that will be compressed by a screw. |
| Mini SPDT toggle switch | BOM states up to 1 A at 24 V. | Use only as a low-current enable/control input unless a suitable switching design is established. |
| INA219 ±3.2 A breakout | Useful for low-current branches or controlled single-channel measurements; inadequate for the possible 11 A combined motor stall current. | Define its measurement location and fuse it for that branch. |
| DROK adjustable buck converter | Selected by Q7 for the mobile Raspberry Pi power branch; exact variant and physical capability remain unvalidated. | Set to 5.10 V and complete the Q7 staged regulation, thermal, startup, and load tests before connecting the Pi. Do not use it for the motor branch. |
| Official Raspberry Pi 27 W USB-C supply | Appropriate for early bench work. | Keep it independent of motor power during initial bring-up. |
| Adafruit USB Mini Hub with Power Switch `#2998` | Four-port bus-powered USB 2.0 hub with one switch for all downstream ports; owner-reported as owned but omitted from BOM REV 02. Its 1.35 mm external jack is directly tied to USB 5 V. | Connect its captive USB-A lead to one black Pi USB 2.0 port and use one marked downstream socket for `#954`/BNO055. Leave the other three sockets spare and the external-power jack empty. It adds ports, not current budget. |

**Wire verdict:** Q9 assigns the owned Elegoo leads to low-current downstream
wiring, with the special four-lead Pi-power arrangement subject to Stage 2B
rejection criteria. The five-pin JST-SH cables have no matching installed
endpoint and the STEMMA QT cables remain spare for future I2C experiments.
The motors' factory leads remain usable. Use 16 AWG copper for the battery
trunk and battery-side branches, the selected 14 AWG inline fuse holder, and
no thin jumper or JST-SH lead in a motor or battery-side path.
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

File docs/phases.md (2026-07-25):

**DIRECTIVE FOR AI ASSISTANTS:** This document tracks phase plans and current task status. It does NOT contain architectural decisions — see `architecture.md` for hardware, software stack, and key decisions. Work only one unchecked item at a time and stop for approval after each. Use checkboxes to track progress. If this document conflicts with a user request, flag it rather than silently overriding.
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

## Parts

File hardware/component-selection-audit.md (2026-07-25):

# Component Selection Audit

**Status:** Motor/driver/IMU/wheel selection history complete; broader hardware revalidation remains in progress

**Started:** 2026-07-16

This document reconstructs how the Phase 1 hardware decisions were made, checks
the claims against primary sources, and separates historical rationale from
verified design facts. It is intentionally not a replacement wiring diagram or
final component recommendation. Current candidate feedback and provisional
recommendations are maintained in the
[Stage 2 hardware decision record](stage-2-hardware-decision-record.md).

## Context and Responsibility

Nathan supplied the source chat after the project documents were found to
contain an incompatible one-channel motor driver and several unverified power
assumptions. At the time of the chat, Nathan was asking introductory questions
and relying on Claude Code to identify products, perform calculations, and
explain the system. A response such as "Sounds good" records acceptance of the
assistant's recommendation; it does not mean Nathan independently verified the
part number, specifications, or equations.

Claims from the old chat and generated summaries are therefore historical
inputs, not validated engineering evidence.

## Evidence Batch 1: Motor and Driver Selection

The supplied chat appears to be from the January 26, 2026 component-selection
work that produced `robotics_project_summary_v5.md`.

### Decision chain in the chat

1. Claude correctly identified the Adafruit DRV8871 as a single H-bridge and
   correctly said that differential drive requires two independent motor
   channels.
2. Claude proposed a "Pololu Dual G2 High-Power Motor Driver 18v25" and described
   it as one board with two 4.5 A channels and 25 A peak capability.
3. The subsequent torque calculation silently changed that name to "Pololu G2
   High-Power 18v17" while retaining the claim that it had two 4.5 A channels.
4. Nathan accepted the recommendation based on that explanation.
5. Claude stated that the selection was finalized and ready to order.
6. The generated v5 summary then listed one real Pololu `#2991` while continuing
   to call it a dual driver with per-channel specifications.

This is the origin of the motor-driver failure: properties from several product
families were combined into a product description that does not exist, and a
real single-channel part number was later attached to it.

### What this excerpt alone does not explain

The chat's final recap names:

- motor `#4751`;
- a BNO085 IMU;
- 65 mm Phase 1 wheels and 80 mm Phase 2 wheels.

The generated v5 summary instead names:

- motor `#4753`;
- a BNO055 IMU;
- 80 mm wheels for both phases.

Those later transitions are not present in the assistant's prose recap, but the
same supplied conversation says Claude edited v5. Comparing that conversation
with the generated v5 file is sufficient to establish the mismatch; another
transcript is not required to understand the failure.

## Evidence Batch 2: Archived Project Summaries

All seven summaries in `docs/_archive/` were reviewed in sequence. They provide
some additional rationale, but they do not contain the source conversation or
manufacturer evidence needed to validate the choices.

### Version timeline

| Version | Hardware-selection state | New evidence relevant to this audit |
|---|---|---|
| v1 | General project concept | No motor, driver, IMU, or wheel selection. |
| v2 | Requirements and candidate families | Introduces two Pololu 37D motors, a Pololu MC33926-or-G2 driver choice, 3 kg maximum mass, 65 mm wheels, and 0.3-0.7 m/s target speed. All remain TBD. |
| v3 | Same as v2 | No relevant component-selection change. |
| v4 | Selection explicitly deferred | The January 24 log says motor selection will wait until after Ubuntu setup and ROS 2 fundamentals. Driver remains MC33926 family vs. G2 series. |
| v5 | All components declared finalized | In one revision, the summary adds `#4753`, one `#2991`, BNO055 `#4646`, 80 mm wheels, the torque/current claims, and the completed shopping carts. |
| v6 | Hardware copied unchanged | Adds a directive calling the summary the single source of truth. It adds no new hardware verification. |
| v7 | Hardware copied unchanged | Adds the four-stage implementation roadmap, including a direct jump from CAD/firmware/wiring to real driving. It adds no hardware-validation stage. |

The important discontinuity is therefore v4 to v5. No archived intermediate
summary records the individual checks that would have been needed to move from
TBD components to a validated system.

### Motor SKU transition

None of the archived summaries mentions `#4751`. The first archived finalized
selection in v5 identifies the intended 50:1 motor as `#4753`, which is the
correct Pololu item number for that ratio.

The v5 summary nevertheless carries forward the approximately 0.75 N m stall
torque from the earlier chat. That value is near the 19:1 motor's rating, not the
2.06 N m extrapolated stall torque of `#4753`. The best-supported interpretation
is that Claude's file edit corrected the item number to match the intended 50:1
ratio while its prose recap still said `#4751` and the associated specifications
and calculations were not refreshed. The user-provided conversation and v5 file
together establish this; the exact internal mechanism of the inconsistent edit
does not need a separate source chat.

### IMU transition

The v5 progress log says BNO055, BNO085, and MPU6050 were evaluated and records
the following rationale for choosing the BNO055:

- claimed better ROS 2 support than BNO085;
- mature drivers and documentation;
- built-in sensor fusion;
- STEMMA QT connection;
- usefulness for odometry fusion and eventual balancing.

This explains the stated reason for the BNO085-to-BNO055 change. The original
summary did not include links, driver/package names, compatibility testing, or
an interface review. The ROS 2 ecosystem portion has now been checked
independently below; physical compatibility and operation still require bench
validation.

### Independent ROS 2 ecosystem check

The narrow claim that BNO055 had the more mature and convenient ROS 2 software
path is supported.

At the January 2026 decision date:

- `flynneva/bno055` had ROS 2 release history going back to 2021 and released
  Humble packages from 2023 and 2024;
- the package supported both I2C and UART, published standard ROS messages, and
  documented parameters, calibration, topics, launch, and source builds;
- `bnbhat/bno08x_ros2_driver` was much newer, with its initial 0.1.0 release
  dated July 13, 2025;
- the BNO08x driver was source-build oriented, indexed for Humble but not
  released into the ROS distribution, with only I2C implemented.

For the current ROS 2 Jazzy project:

- `bno055` 0.5.0 is released and built as a Jazzy/Noble binary package;
- its Jazzy API and package documentation are generated on `docs.ros.org`;
- ROS Index still marks `bno08x_driver` as unreleased and shows Humble rather
  than Jazzy as its indexed distribution;
- the BNO08x source driver now documents up to 400 Hz IMU output, but UART and
  SPI remain unimplemented.

**Verdict:** "BNO055 has better ROS 2 package availability and a more mature
integration path for this project" was and remains a fair claim. It does not
prove that BNO055 is the technically better IMU. BNO085 is newer and its source
driver exposes higher rates, but choosing it would currently require accepting
more integration and maintenance work. The owned BNO055 is therefore a
reasonable Phase 1 choice, subject to bench testing on the Pi and validation of
message conventions, calibration behavior, and update rate.

### Wheel transition

The v5 progress log contains both states of the decision:

1. The morning entry assigns 65 mm wheels to Phase 1 and 80 mm wheels to Phase 2.
2. The afternoon entry changes to 80 mm wheels for both phases to save about
   $8-$10 and eliminate the mechanical wheel swap.

The afternoon decision cites the old 5.9 Phase 1 and 1.26 Phase 2 torque margins
as proof that the simplification is safe. The archive therefore explains why
80 mm wheels were ordered, but the Phase 2 support for that choice remains
invalid because it comes from the dimensionally incorrect balancing calculation.

### Motor-driver transition

The archive provides no additional valid explanation for the driver choice.
Instead, v5 contains the contradiction in two forms at the same time:

- the shopping list orders one `#2991`, correctly using the real product's name
  without the word "Dual";
- the key-decisions and progress-log sections call it a "Pololu Dual G2
  High-Power 18v17" with 4.5 A continuous per channel.

This confirms that the order was generated from a real catalog item while the
system reasoning still used the invented dual-channel description. Versions 6
and 7 copy the contradiction without revisiting it.

### How the error became authoritative

Version 5 labels the design performance "validated" and the shopping carts
"finalized," but records no datasheet review, schematic, interface table, test,
or acceptance criterion. Version 6 then adds a directive requiring future
assistants to treat the summary as the single source of truth. Version 7 builds
the implementation roadmap on top of it and schedules chassis CAD, firmware,
and wiring without an intervening component or electrical validation gate.

The archive therefore explains how an unsupported chat recommendation became
project scope: repetition and document status replaced verification.

### Remaining provenance gaps

The archived summaries still do not establish:

- where the nonexistent 4.5 A-per-channel G2 specification came from;
- any channel-count check before ordering `#2991`;
- any review of encoder voltage, Due `VIN`, Raspberry Pi GPIO power, switching,
  fusing, wiring, or protection.

The motor-SKU mismatch is sufficiently explained by the supplied conversation
and generated file, and the BNO055 ROS 2 claim has now been independently
checked. The remaining questions require other contemporaneous evidence or new
engineering validation.

## Claim Audit

| Historical claim | Assessment | Corrected interpretation |
|---|---|---|
| DRV8871 is a single H-bridge for one motor | Correct | Two boards would be needed for two independently driven motors. |
| DRV8871 supplies 3.6 A continuously and 6.5 A peak | Incorrect | Adafruit and TI specify 3.6 A peak. The Adafruit breakout ships with an approximately 2 A current-limit setting. Continuous capability depends on thermal conditions. |
| Lack of "built-in encoder support" is a DRV8871 disadvantage | Misleading | A motor driver normally drives motor current; the encoder connects separately to the MCU. The proposed Pololu G2 drivers also do not decode the motor encoders. |
| A dual board inherently uses fewer motor-control GPIO pins | Not established | Independent motors still require independent commands. Exact pin count depends on the driver's control interface and which enable, fault, and current-sense signals are used. |
| Pololu Dual G2 18v25, two 4.5 A channels, 25 A peak | Nonexistent combination | Pololu `#2994` is a single-channel G2 18v25. Actual dual G2 products have different names, ratings, form factors, and part numbers. |
| Pololu Dual MC33926 provides about 3 A continuous and 5 A peak per channel | Substantially correct | Pololu specifies almost 3 A continuous and 5 A peak per channel, subject to strong thermal limitations. Price claims in the chat are historical and were not used for validation. |
| `#4751` is the 50:1 encoder motor | Incorrect | `#4751` is the 19:1 encoder version. The purchased 50:1 encoder motor is `#4753`. |
| The 50:1 motor has about 0.75 N m stall torque | Incorrect for `#4753` | Pololu lists 21 kg cm, approximately 2.06 N m, extrapolated stall torque at 12 V for `#4753`. The old value is close to the 19:1 motor's rating and followed the SKU mix-up. |
| Seventy percent of stall torque is a suitable usable-continuous value | Unsafe assumption | Pololu recommends continuous loads around 25% or less of stall torque/current and warns that stalls can quickly damage the motor or gearbox. Stall torque is not an operating rating. |
| One `#2991` can drive both differential-drive motors independently | Incorrect | `#2991` contains one H-bridge for one bidirectional brushed DC motor. The robot needs two independent H-bridges. |
| `#2991` is rated 4.5 A continuous per channel | Incorrect | Pololu specifies one channel and 17 A continuous under its stated test conditions. That rating does not create a second channel. |
| Seven amps is the peak current for both `#4753` motors | Incorrect terminology | Each motor has a 5.5 A theoretical stall current at 12 V, or 11 A combined. Seven amps represented the chat's assumed 70%-torque operating point, not the system peak. |

## Recalculation of the Navigation Example

The original navigation example used:

- mass: 1.5 kg;
- rolling-resistance coefficient: 0.015;
- acceleration: 0.7 m/s^2;
- incline: 10 degrees;
- two equally loaded driven wheels.

Correcting the missed division by two in the rolling-resistance term gives the
following simultaneous per-motor torque estimates:

| Wheel diameter | Rolling | Acceleration | 10-degree incline | Total per motor |
|---|---:|---:|---:|---:|
| 65 mm | 0.0036 N m | 0.0171 N m | 0.0415 N m | 0.0622 N m |
| 80 mm | 0.0044 N m | 0.0210 N m | 0.0511 N m | 0.0765 N m |

For `#4753`, the extrapolated 12 V stall torque is about 2.06 N m. A simple
linear voltage scaling gives about 1.90 N m at 11.1 V. Twenty-five percent is
about 0.48 N m. This is not a formal continuous rating, but it is consistent with
Pololu's general recommendation to keep continuous load near or below 25% of
stall torque.

Under these simplified assumptions, the navigation torque margin is still
large: approximately 7.7 at 65 mm and 6.2 at 80 mm before accounting for losses,
load imbalance, transients, traction, manufacturing variation, or thermal
conditions. The Phase 1 motor conclusion therefore remains plausible even
though the original calculation reached it using the wrong SKU, wrong stall
torque, and unsafe 70% operating assumption.

At 11.1 V, linear no-load-speed scaling gives approximately 185 RPM. That is
about 0.63 m/s with 65 mm wheels and 0.77 m/s with 80 mm wheels. The chat's
150 RPM "realistic" loaded speed was an unsupported assumed operating point,
not a validated speed prediction.

## Why the Balancing Calculation Is Invalid

The chat calculated a supposed per-wheel balancing torque using:

`m * g * h * sin(theta) / wheel_radius`

The numerator is torque in N m. Dividing it by wheel radius produces force in N,
not another torque. With the stated 1.5 kg mass, 0.06 m center-of-mass height,
and 10-degree angle, the numerator is about 0.153 N m. Dividing by a 0.0325 m
radius gives 4.72 N, not 0.47 N m. The chat both mislabeled the units and appears
to have introduced a factor-of-ten arithmetic error.

More importantly, a self-balancing robot cannot ultimately be validated with a
static torque comparison. It is a coupled wheeled inverted pendulum. When the
project reaches full Phase 2 design and validation, that work can include:

- body center of mass above the wheel axle;
- body, wheel, and motor inertia;
- motor torque-speed and electrical dynamics;
- wheel radius and robot translation;
- gearbox efficiency and backlash;
- available voltage and current limiting;
- sensor latency/noise and control-loop rate;
- desired disturbance recovery and operating envelope.

The claim that a low center of gravity is automatically better is also not a
valid balancing rule. The center of mass must be above the axle for an inverted
pendulum, and changing its height changes both gravitational torque and falling
dynamics. Battery and board placement must come from the dynamic model, not the
old static calculation.

Phase 1 Stage 2A Q2 did not attempt that full validation. Its later preliminary
dynamic screen found the owned motors and 80 mm wheels
plausible across illustrative scenarios. Nathan requires their reuse while
plausible. This does not validate final Phase 2 mass, center-of-mass placement,
or physical balancing performance; those properties are intentionally deferred
until Phase 2 exists.

## Current Documented Inventory State

As of this audit, the repository and BOM document ownership of:

- two Pololu 50:1 37D encoder gearmotors, item `#4753`;
- one Pololu G2 High-Power Motor Driver 18v17, item `#2991`;
- one pair of 80 mm Pololu wheels;
- one Adafruit BNO055 breakout, item `#4646`.

This inventory has only one of the two independently controllable motor channels
required by Phase 1 differential drive. The owned `#2991` headers have since
been confirmed as loose and unsoldered. Stage 2A Q1 subsequently established
that user soldering of off-the-shelf products is acceptable, so the headers can
be installed; this does not resolve the board's one-channel limitation. The
owned wiring has been classified in the
[Stage 2 hardware decision record](stage-2-hardware-decision-record.md). Q9
later accepted JST-SH/STEMMA and Elegoo leads for downstream low-current
wiring, plus four short parallel Elegoo leads for the DROK-to-Pi path subject
to Stage 2B load rejection criteria. The factory motor harnesses are usable;
motor and battery-side paths still exclude thin jumper/JST-SH wire and use the
Q9 16 AWG harness design.

## Decisions Still Required

The authoritative resolution order is
[Stage 2A in the phase plan](../docs/phases.md#stage-2a-resolve-hardware-questions-in-order).
Detailed
candidate findings—including the provisional recommendation not to purchase a
second `#2991`—are in the
[Stage 2 hardware decision record](stage-2-hardware-decision-record.md). No
provisional recommendation becomes an architectural decision until its stated
manufacturer review and bench acceptance criteria pass.

## Process Finding

The user asked reasonable early-stage questions. The failure occurred because
assistant-generated recommendations were marked "finalized" and converted into
orders without a part-number-to-datasheet check, dimensional check of the
equations, or interface/channel-count review.

Future component decisions require four distinct states:

1. proposed;
2. manufacturer-verified;
3. procured and physically identified;
4. bench-validated in the intended interface.

Agreement in a chat advances none of those states by itself.

## Primary Sources

- [Pololu G2 and H2 motor-driver product families](https://www.pololu.com/category/254/g2-and-h2-high-power-motor-drivers)
- [Pololu G2 High-Power Motor Driver 18v17, item #2991](https://www.pololu.com/product/2991)
- [Pololu G2 High-Power Motor Driver 18v25, item #2994](https://www.pololu.com/product/2994)
- [Pololu Dual MC33926 Motor Driver Carrier, item #1213](https://www.pololu.com/product/1213)
- [Pololu 50:1 37D encoder gearmotor, item #4753](https://www.pololu.com/product/4753)
- [Adafruit DRV8871 breakout, item #3190](https://www.adafruit.com/product/3190)
- [MIT Underactuated Robotics: cart-pole dynamics](https://underactuated.mit.edu/acrobot.html#cart_pole)
- [ROS 2 Jazzy bno055 package documentation](https://docs.ros.org/en/jazzy/p/bno055/)
- [ROS Index: bno055 package](https://index.ros.org/p/bno055/)
- [bno055 ROS release history](https://github.com/ros2-gbp/bno055-release)
- [ROS Index: bno08x_driver repository](https://index.ros.org/r/bno08x_driver/)
- [BNO08x ROS 2 source driver](https://github.com/bnbhat/bno08x_ros2_driver)

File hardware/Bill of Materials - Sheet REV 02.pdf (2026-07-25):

Item | Quantity Unit Cost Source | Phase | Status | Notes
Electronics
Raspberry Pi 5 | 1 | $115.92 Amazon (https://www.amazon.com/dp/B0CK2FCG1K?ref=ppx_yo2ov_dt_b_fed_asin_title) | 1 Own | Main computer
RPi 5 Power Supply | 1 | $14.46 Vilros (https://vilros.com/products/raspberry-pi-5-official-power-supply?variant=40067049979998&src=raspberrypi) | 1 Own | 27W USB-C, 5.1V, 5A
M.2 HAT+ | 1 | $23.99 Amazon (https://www.amazon.com/dp/B0CRDY6Q3C?ref=ppx_yo2ov_dt_b_fed_asin_title) | 1 Own | Intermediary between RPi 5 and NVME for SSD
Active Cooler | 1 | $11.89 Amazon (https://www.amazon.com/dp/B0CLXZBR5P?ref=ppx_yo2ov_dt_b_fed_asin_title) | 1 Own | Thermal management
Raspberry Pi NVMe SSD | 1 | $89.99 Vilros (https://vilros.com/products/raspberry-pi-ssd) | 1 Own | Ubuntu boot drive
64 GB SSD | 1 | $0.00 Office | 1 Own | For practicing booting and Linux environment before NVMe SSD arrives
ELEGOO Sensor Kit | 1 | $50.87 Amazon (https://www.amazon.com/dp/B01EWNUUUA?ref_=ppx_hzsearch_conn_dt_b_fed_asin_title_4) | 1 Own | Miscellaneous sensors
RPi Camera Module 3 (Standard) | 1 | $40.00 Vilros (https://vilros.com/products/raspberry-pi-camera-3?variant=39984853155934) | 1 Own | Camera with 12-megapixel Sony IMX708 image sensor module
Arduino Due | 1 | $0.00 Office | 1 Own | MCU
Arduino Mega Prototype Shield V3 | 1 | $0.00 Elegoo Kit | 1 Own | For wiring and pass through of the motor controller
Adafruit 9-DOF Absolute Orientation IMU
Fusion Breakout - BNO055 - STEMMA QT
/ Qwiic | 1 | $29.95 Adafruit (https://www.adafruit.com/product/4646) | 1 Own

9-DOF sensor, MEMS accelerometer, magnetometer, and gyroscope, and putting them on a single die with a high-speed ARM Cortex-M0 based processor to digest all the sensor data

DROK DC Buck Converter, 5.3V-32V to
1.2V-32V 12A Adjustable Power Supply | 1 | $17.49 Amazon (https://www.amazon.com/dp/B078Q1624B?ref=ppx_yo2ov_dt_b_fed_asin_title&th=1) | 1 Own

Adjustable voltage buck converter for the RasPi 5. I needed it to be adjustable instead of set at 5V because it is reported the RasPi 5 can brown out when it gets marginally less than 5V.

Pololu Dual VNH5019 Motor Driver Shield
for Arduino | 1 | $39.95 Pololu (https://www.pololu.com/product/2507) | 1 Ordered

This shield makes it easy to control two high-power DC motors with your Arduino or Arduino-compatible board. Its dual robust VNH5019 motor drivers operate from 5.5 to 24 V and can deliver a continuous 12 A (30 A peak) per motor, or a continuous 24 A (60 A peak) to a single motor connected to both channels. These great drivers also offer current-sense feedback and accept ultrasonic PWM frequencies for quieter operation. The Arduino pin mappings can all be customized if the defaults are not convenient, and the motor driver control lines are broken out along the left side of the shield for general-purpose use without an Arduino.

74LVC245 - Breadboard Friendly 8-bit
Logic Level Shifter | 2 | $1.50 Adafruit (https://www.adafruit.com/product/735) | 1 Ordered

This chip solves the problem of how to interface 3.3V logic devices to a 5.0V logic chip such as the Arduino. Most 3.3V devices do not like being run with 5V signals and can be damaged or flaky. The 74LVC245 is designed so that even when it runs at 1.8V, it still happily accepts 5V signals in one pin and converts it to a lower logic level on the opposite pin. This chip is only for digital signals, it doesn't convert analog signals (you need an op-amp for that). It has 8 pipes it can convert but it won't work with bi-directional/pull-up based devices such as I2C or 1-Wire. It does work great for SPI, Serial, Parallel bus, and other logic interfaces. IC Socket - for 20-pin 0.3" Chips - Pack of
3 | 1 | $0.95 Adafruit (https://www.adafruit.com/product/2204) | 1 Ordered

For connecting the Logic Level Shifter to the Due for Encloder communication
TBD RPLidar A1M8 | 1 | $0.00 | 2
TBD 18650 Battery Pack (3S) | 1 | $0.00 | 3
TBD Battery Monitor | 1 | $0.00 | 3

Item | Quantity | Unit Cost | Source | Phase | Status | Notes
TBD Emergency Stop Button | 1 | $0.00 | 3
Arduino Mega 2560 | 1 | $0.00 Elegoo Kit | 1 Own | Motor controller

Mechanical Components

50:1 Metal Gearmotor 37Dx70L mm 12V
with 64 CPR Encoder (Helical Pinion) | 2 | $70.95 Pololu (https://www.pololu.com/product/4753) | 1 Own

12V brushed DC motor with 16mm long, 6mm diameter D-shaped shaft, and encoder

Pololu Wheel 80×10mm Pair - Black | 1 | $8.75 Pololu (https://www.pololu.com/product/1430) | 1 Own

silicone tires and measure 80 mm (3.15″) in diameter, and they press-fit onto 3mm D shafts
Pololu Universal Aluminum Mounting Hub
for 6mm Shaft, #4-40 Holes (2-Pack) | 1 | $12.95 Pololu (https://www.pololu.com/product/1083) | 1 Own

Universal aluminum mounting hubs allow you to mount custom wheels and mechanisms to 6 mm diameter motor shafts

Pololu Ball Caster with 3/4″ Plastic Ball | 1 | $5.49 Pololu (https://www.pololu.com/product/954) | 1 Own

Light ball caster uses a 3/4″ diameter plastic ball. The height of the assembled kit ranges from 0.9″ to 1.2″, depending on the combination of included spacers

Mini Panel Mount SPDT Toggle Switch | 1 | $0.95 Adafruit (https://www.adafruit.com/product/3221) | 1 Own

Toggle switch that can power on and off the robot. Up to 1A at 24V recommended.
TBD Chassis | 1 | $0.00 3D Printed | 1

Wiring and Connectors

JST SH-Style Cable, 5-Pin, Female-
Female, 16cm | 3 | $3.06 Pololu (https://www.pololu.com/product/5534) | 1 Own

This 5-conductor, 16 cm (6.3″) cable has 28 AWG wires and 5-pin female JST SH-type connectors (1mm pitch) on both ends

JST SH-Style Cable, 5-Pin, Single-Ended

Female, 12cm | 3 | $1.77 Pololu (https://www.pololu.com/product/5530) | 1 Own | This 5-conductor, 12 cm (4.5″) cable has 28 AWG wires and a 5-pin
| | | | female JST SH-type connector (1mm pitch) on one end. The other ends
| | | | of the wires are unterminated; they can be cut to length to match your
| | | | application.
2x20 Extra Tall Female 0.1" Pitch Stacking
Header | 8 | $9.79 Amazon (https://www.amazon.com/dp/B0DKTKPCHH?ref=ppx_yo2ov_dt_b_fed_asin_title) | 1 Own | 23mm tall header that actually passes through the M.2 HAT+
STEMMA QT / Qwiic JST SH 4-pin Cable -
100mm Long | 3 | $0.95 Adafruit (https://www.adafruit.com/product/4210) | 1 Own | fitted with JST-SH female 4-pin connectors on both ends
STEMMA QT / Qwiic JST SH 4-Pin Cable -
200mm Long | 2 | $1.25 Adafruit (https://www.adafruit.com/product/4401) | 1 Own | fitted with JST-SH female 4-pin connectors on both ends
16AWG Silicone Wire 10ft | 1 | $5.55 Amazon (https://www.amazon.com/dp/B0D9693V7D?ref_=ppx_hzod_title_dt_b_fed_asin_title_0_3&th=1) | 1 Own | Will use to connect the battery to the motors and the buck converter
ALITOVE 3 Wire Splice Connectors 10pcs | 1 | $7.99 Amazon (https://www.amazon.com/dp/B0DJSCX3QB?ref=ppx_yo2ov_dt_b_fed_asin_title&th=1) | 1 Own | For quick prototyping wire harnesses (avoids soldering and crimping)
Weewooday 10 Pieces 12-Position Dual
Row White Screw Terminal Strip | 1 | $6.99 Amazon (https://www.amazon.com/dp/B08NGBQWWT?ref=ppx_yo2ov_dt_b_fed_asin_title&th=1) | 1 Own | For quick prototyping wire harnesses (avoids soldering and crimping)

Item | Quantity | Unit Cost | Source | Phase | Status | Notes
Waterproof Medium Inline Fuse Holder | 1 | $4.89 Amazon (https://www.amazon.com/dp/B0DKJJJYX1?ref_=ppx_hzod_title_dt_b_fed_asin_title_0_5&th=1) | 1 Own | To place near the battery for downstream electrical protection
80Pcs Standard Fuse Kit | 1 | $4.99 Amazon (https://www.amazon.com/dp/B0FC5LW7LS?ref_=ppx_hzod_title_dt_b_fed_asin_title_0_4) | 1 Own | Will use the 10A fuse with the inline fuse holder

Equipment

FNIRSI® HS-02 Intelligent Soldering Iron

| 1 | $99.99 Fnirsi (https://www.fnirsi.com/products/hs-02?variant=46414045708506) | 1 Own | HS-02A is equipped with 6 soldering iron tips (K, KU, JS, I, C2, B). HS-
| | | | 02B is equipped with 3 soldering iron tips (I, IS, K). The integrated design
| | | | allows the soldering iron to heat up quickly and maintain a stable
| | | | temperature. And the 100 W charging adapter allows you to use it
| | | | immediately.
Solder 0.032" | 1 | $5.45 Amazon (https://www.amazon.com/dp/B005T8N3YI?ref_=ppx_hzod_title_dt_b_fed_asin_title_0_0&th=1) | 1 Own | RA Flux Core
Soldering Iron Tip Cleaner | 1 | $5.99 Amazon (https://www.amazon.com/dp/B09W2G3RVV?ref_=ppx_hzod_title_dt_b_fed_asin_title_0_1&th=1) | 1 Own
Solder Wick & Solder Wire & Solder
Sucker | 1 | $8.99 Amazon (https://www.amazon.com/dp/B09JVMTMY4?ref_=ppx_hzod_title_dt_b_fed_asin_title_0_2&th=1) | 1 Own

NICE-POWER DC Power Supply Variable

30V 10A | 1 | $39.87 Amazon (https://www.amazon.com/dp/B0CDW12H3X?ref=ppx_yo2ov_dt_b_fed_asin_title&th=1) | 1 Own | Adjustable Switching Regulated DC Bench Power Supply with Output
| | | | Switch High Precision 4-Digit LED Display, Benchtop Lab Power Supplies
| | | | with 5V/2A USB Port

Fun Unecessary Pick Ups

Insulated Silicone Rework Mat - 34cm x

23cm Work Surface - Blue | 1 | $9.95 Adafruit (https://www.adafruit.com/product/3536) | 0 Own | Non-slip, ESD safe surface to prevent damaging boards accidentally on
| | | | my plastic desk surface (in the middle of a dry NYC winter)
INA219 High Side DC Current Sensor
Breakout - 26V ±3.2A Max - STEMMA QT | 1 | $9.95 Adafruit (https://www.adafruit.com/product/904) | 0 Own | Current measuring chip to use instead of blowing out multimeters
Adafruit APDS9960 Proximity, Light, RGB,
and Gesture Sensor - STEMMA QT / Qwiic | 1 | $7.50 Adafruit (https://www.adafruit.com/product/3595) | 0 Own | Basic gesture sensing, RGB color sensing, proximity sensing, or ambient
| | | | light sensing
USB to TTL Serial Cable - Debug /
Console Cable for Raspberry Pi | 1 | $9.95 Adafruit (https://www.adafruit.com/product/954) | 0 Own | Easiest way ever to connect to your microcontroller/Raspberry Pi/WiFi
| | | | router serial console port

GPIO Header for RaspberryPi A+/B+/Pi

2/Pi 3 - Tall 2x20 Female Header | 1 | $2.95 Adafruit (https://www.adafruit.com/product/1992) | 1 Own | TOO SHORT
| | | | This spacer will extend the headers through the M.2 HAT+ on my RasPi 5
| | | | so I can actually use them

GPIO Stacking Header for Pi A+/B+/Pi 2/Pi

3 - Extra-long 2x20 Pins | 1 | $2.75 Adafruit (https://www.adafruit.com/product/2223) | 1 Own | TOO SHORT
| | | | This spacer will extend the headers through the M.2 HAT+ on my RasPi 5
| | | | so I can actually use them
Pololu G2 High-Power Motor Driver 18v17 | 1 | $44.95 Pololu (https://www.pololu.com/product/2991) | 1 Own | Dual motor driver, 6.5V-30V, 17A

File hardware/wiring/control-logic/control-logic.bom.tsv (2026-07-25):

Id | Description | Qty | Unit | Designators
1 | Connector, Arduino Due, Installed power, control, and feedback pins, 17 pins | 1 |  | DUE1
2 | Connector, Owned 0.1 uF ceramic capacitor, 104 decoupling capacitor, 2 pins | 1 |  | C1
3 | Connector, Owned Adafruit #735 74LVC245 octal bus transceiver, 3.3V encoder level translator in #2204 socket on Mega prototype carrier, 20 pins | 1 |  | U1
4 | Connector, Pololu #2507 Dual VNH5019 motor driver, Logic header, 12 pins | 1 |  | DRV1
5 | Owned Adafruit #2204 20-pin IC socket | 1 |  | U1
6 | Owned Arduino Mega Prototype Shield V3, Translator and encoder fanout carrier | 1 |  | U1

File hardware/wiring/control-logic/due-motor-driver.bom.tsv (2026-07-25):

Id | Description | Qty | Unit | Designators
1 | Connector, Arduino Due, Motor-control pins, 12 pins | 1 |  | DUE1
2 | Connector, Pololu #2507 Dual VNH5019 motor driver, Logic header, 12 pins | 1 |  | DRV1

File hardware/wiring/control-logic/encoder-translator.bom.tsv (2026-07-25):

Id | Description | Qty | Unit | Designators
1 | Connector, Arduino Due, Encoder interface pins, 7 pins | 1 |  | DUE1
2 | Connector, Owned 0.1 uF ceramic capacitor, 104 decoupling capacitor, 2 pins | 1 |  | C1
3 | Connector, Owned Adafruit #735 74LVC245 octal bus transceiver, 3.3V translator in #2204 socket on Mega prototype carrier, 20 pins | 1 |  | U1
4 | Owned Adafruit #2204 20-pin IC socket | 1 |  | U1
5 | Owned Arduino Mega Prototype Shield V3, Translator and encoder fanout carrier | 1 |  | U1

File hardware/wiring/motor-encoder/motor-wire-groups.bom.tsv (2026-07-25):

Id | Description | Qty | Unit | Designators
1 | Connector, Adafruit #735 74LVC245 encoder level translator, Encoder-side A inputs, 4 pins | 1 |  | U1
2 | Connector, Arduino Due, Encoder power rails, 2 pins | 1 |  | DUE1
3 | Connector, Pololu Dual VNH5019 motor driver, #2507 motor-output terminals, 4 pins | 1 |  | DRV1

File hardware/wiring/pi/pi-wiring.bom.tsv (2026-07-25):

Id | Description | Qty | Unit | Designators
1 | Connector, Adafruit BNO055, UART-mode breakout, 6 pins | 1 |  | BNO1
2 | Connector, Arduino Due, Programming micro-USB port, 4 pins | 1 |  | DUE1
3 | Connector, DROK 5.10 V converter, 2 pins | 1 |  | PS1
4 | Connector, Owned 2x20 extra-tall female 0.1-inch stacking header, 23 mm GPIO extension; four used contacts shown, 4 pins | 1 |  | H1
5 | Connector, Owned Adafruit #2998 USB Mini Hub with Power Switch, Bus-powered 4-port USB 2.0 hub with captive USB-A upstream lead, 12 pins | 1 |  | HUB1
6 | Connector, Raspberry Pi 5, Power and external interfaces, 22 pins | 1 |  | PI1

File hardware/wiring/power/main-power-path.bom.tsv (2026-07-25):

Id | Description | Qty | Unit | Designators
1 | Connector, Arduino Due, Programming micro-USB port, 4 pins | 1 |  | DUE1
2 | Connector, DROK 5.10 V converter, 4 pins | 1 |  | PS1
3 | Connector, Owned 2x20 extra-tall female 0.1-inch stacking header, 23 mm Pi GPIO extension; four used contacts shown, 4 pins | 1 |  | H1
4 | Connector, Owned ALITOVE 3-wire splice connector, Battery-negative distribution, 3 pins | 1 |  | TB1_NEG
5 | Connector, Owned ALITOVE 3-wire splice connector, Fused-positive distribution, 3 pins | 1 |  | TB1_POS
6 | Connector, Owned waterproof medium inline fuse holder, 14 AWG / standard ATO-ATC / 10 A fuse, 2 pins | 1 |  | F1
7 | Connector, Pololu Dual VNH5019 motor driver, #2507 power terminal, 2 pins | 1 |  | DRV1
8 | Connector, Raspberry Pi 5, Power header below H1 and direct USB-A host port, 8 pins | 1 |  | PI1
9 | Owned standard blade fuse from 80-piece kit, 10 A ATO/ATC | 1 |  | F1

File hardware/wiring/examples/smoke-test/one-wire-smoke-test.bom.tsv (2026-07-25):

Id | Description | Qty | Unit | Designators
1 | Cable, 1 x 22 AWG | 0.1 | m | W_TEST
2 | Connector, Test load, 1 pins | 1 |  | LOAD
3 | Connector, Test source, 1 pins | 1 |  | SOURCE

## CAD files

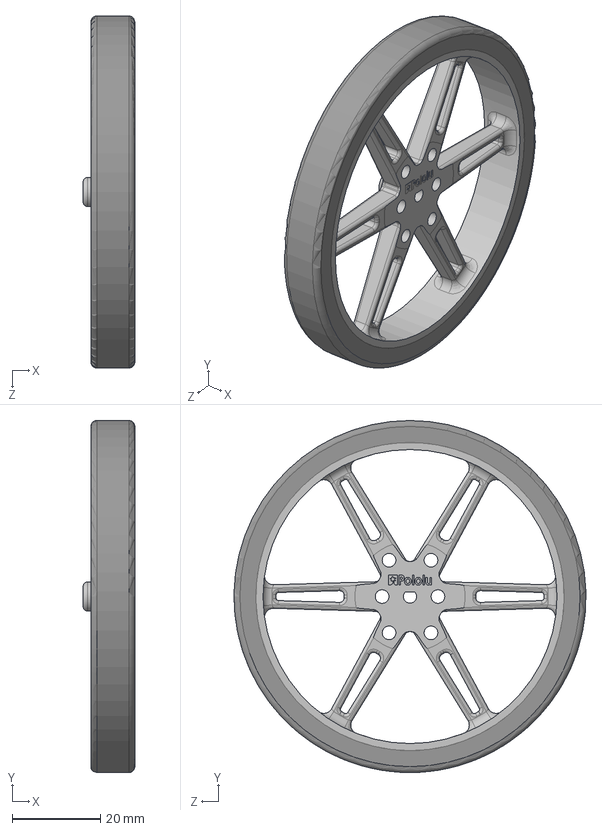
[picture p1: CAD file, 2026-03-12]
hardware/cad/step/pololu-wheel-80x10mm-black.step
11.8 x 80.0 x 80.0 mm

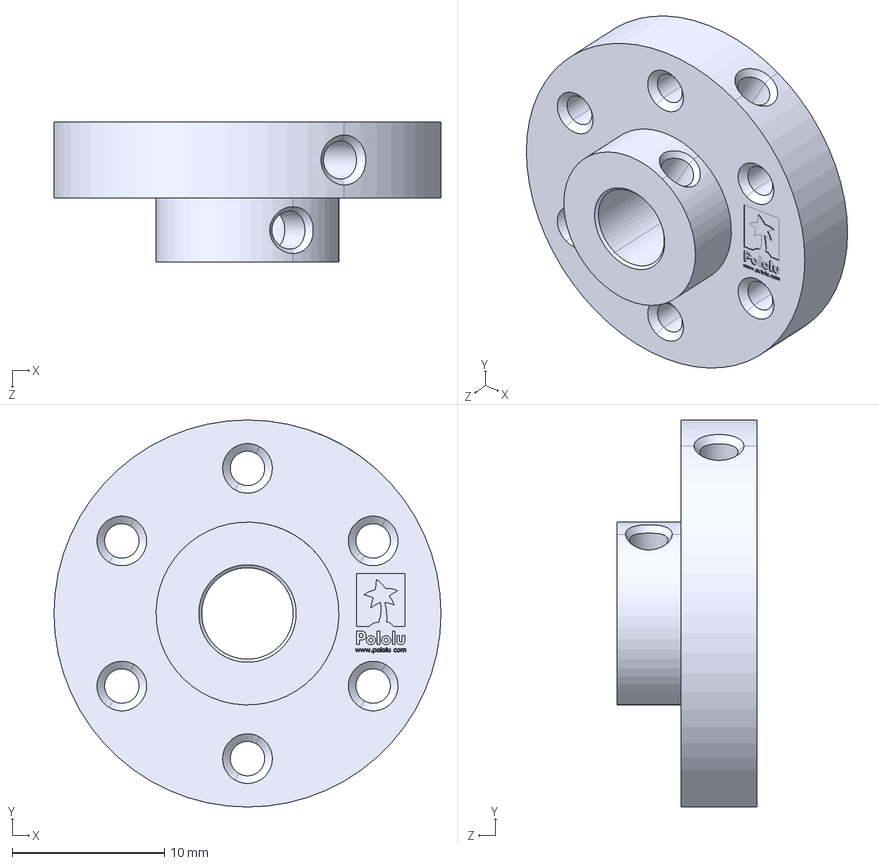
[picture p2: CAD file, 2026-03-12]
hardware/cad/step/pololu-universal-aluminum-mounting-hub-for-6mm-shaft-4-40-holes.step
25.4 x 25.4 x 9.20 mm

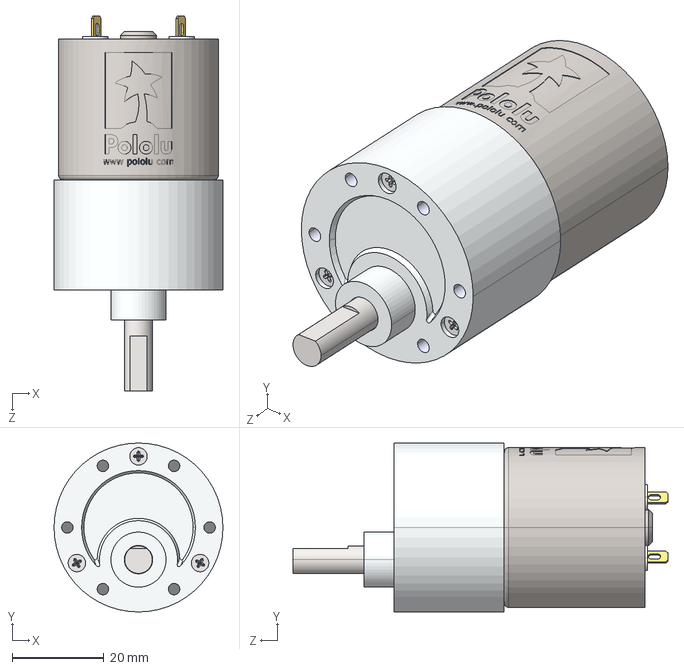
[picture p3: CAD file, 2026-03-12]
hardware/cad/step/37d-gearmotor-50-70.step
36.8 x 36.8 x 81.7 mm

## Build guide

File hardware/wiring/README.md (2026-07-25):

# WireViz Wiring Diagrams

WireViz is installed locally in the repository at `venv/wireviz`. The
environment is ignored by Git and does not modify the Pi's system Python.

Run WireViz from the repository root through the wrapper:

```bash
./scripts/wireviz.sh --version
```

Each diagram has its own subject folder. The editable YAML source and its
generated HTML, PNG, SVG, and bill of materials stay together:

- `power/` — battery, protection, distribution, converter, Pi, and Due path
- `motor-encoder/` — both six-wire motor and encoder groups
- `control-logic/` — complete and focused Due, driver, and translator views
- `pi/` — Pi power alternatives, installed storage/cooling, direct Due and
  future LiDAR links, and the owned `#2998` hub feeding the BNO055 branch
- `examples/smoke-test/` — local installation test only

Connection coverage against the authoritative interface matrix is tracked in
`coverage.md`, which also records where every owned wiring/connector BOM item
is used or why it remains spare.

Render or refresh a diagram from the repository root:

```bash
./scripts/wireviz.sh \
  --format hpst \
  hardware/wiring/power/main-power-path.yml
```

Without `--output-dir`, WireViz writes the generated files beside the YAML
source in that diagram's folder.

Graphviz is a separate WireViz prerequisite. This Pi already provides `dot` at
`/usr/bin/dot`.

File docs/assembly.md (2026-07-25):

# Stage 2B Assembly and Commissioning Guide

This is the step-by-step procedure for
[Stage 2B](phases.md#stage-2b-incremental-bench-build-and-integration).
Electrical decisions come from the [architecture](architecture.md) and
[interface matrix](../hardware/power-signal-interface-matrix.md). Record actual
results in the
[Stage 2 validation log](../hardware/stage-2-validation-log.md); do not put
unit-specific readings in this reusable guide.

Work exactly one numbered gate at a time. Do not begin the next gate until the
current log entry is complete and approved. A failed gate remains unchecked,
the hardware is returned to the gate's safe end state, and the observed
failure is diagnosed before retesting.

## Non-Negotiable Safety Rules

- Disable every source output and verify de-energized state before changing
  wiring. Do not hot-plug motor, encoder, driver, DROK, or GPIO connections.
- Keep meter leads in `COM` and `V/ohm` for voltage, resistance, and continuity
  work. Never place a meter in current mode directly across a source.
- Use the NICE-POWER output-enable control and conservative current limits.
  Do not treat its display as calibrated evidence; corroborate voltage with
  the multimeter.
- Keep both wheels clear of the surface until Gate B18. Secure motors and
  wheels before applying motor power.
- Never intentionally stall a motor, short a driver output, or defeat the
  selected fuse/protection path.
- Connect the Due to only one powered USB host. Connect the Pi by only one
  power method. USB-C and header power must never be present together.
- Never connect a 5 V encoder output directly to a Due input.
- Keep Dupont, JST-SH, STEMMA QT, breadboard contacts, and the white terminal
  strips out of motor and source-current paths. The four-lead Pi arrangement
  is the one explicit exception and must pass Gates B22 and B23.
- Power resistors become burn hazards. Mount them on a nonflammable,
  heat-tolerant base, keep them guarded, and let them cool before handling.
- Stop immediately for smoke, odor, unexpected noise, loose wiring, cable
  snagging, unstable voltage, excessive heating, repeated resets, or a driver
  fault that is not part of the current controlled test.

## Tools and Test Materials

- NICE-POWER `SPS-C3010` 0–30 V, 0–10 A CC/CV supply
- Digital multimeter with DC voltage, resistance, and continuity modes
- Non-contact IR thermometer with a repeatable measurement spot
- FNIRSI HS-02A soldering kit, suitable solder, flux, and tip cleaner
- Wire stripper, small cutters, screwdrivers, and insulated hand tools
- 16 AWG copper bench/load wire and guarded terminal connections
- One 10 Ω, at least 25 W power resistor
- Two 2 Ω, at least 50 W power resistors
- Heat-safe resistor mounting base or heatsink
- 1 kΩ resistor for controlled EN/DIAG-low simulation
- Marker or tape for consistent shaft and temperature reference points
- Scale, calipers, ruler, and basic mechanical inspection tools
- Computer or Raspberry Pi capable of compiling and uploading Arduino Due code

## Standard Evidence

Every gate log entry records:

- date, operator, hardware marking/revision, and connection state;
- firmware commit/configuration and CAD revision where applicable;
- source voltage/current limit and meter identity;
- expected result, actual readings, and observations;
- photograph references where they clarify assembly or meter setup;
- pass/fail, deviations, corrective action, and owner approval.

Firmware created during these gates belongs under
`software/arduino/diffbot_due/`. The commissioning utility belongs at
`software/arduino/tools/commission_due.py`.

## Commissioning Serial Interface

The firmware uses a deliberately small text interface over the Due Programming
USB port at 115200 baud, 8N1. Each command is one ASCII line terminated by
newline:

```text
ARM
DISARM
SET <left_counts_per_second> <right_counts_per_second>
STOP
RESET_FAULT
STATUS
```

The commissioning build additionally accepts:

```text
TEST_PWM <M1|M2> <signed_duty_permille> <duration_ms>
```

The normal telemetry line is:

```text
STATE <milliseconds> <left_count> <right_count> <left_cps> <right_cps> <m1_mA> <m2_mA> <flags>
```

Implementation rules:

- cap input at 96 bytes and reject overflow, extra fields, missing fields,
  non-numeric values, and values outside configured limits;
- start disarmed with both PWM outputs low and both channels coasting;
- accept `ARM` only with zero targets and no latched/physical fault;
- accept `SET` only while armed and fault-free, and refresh the 500 ms
  watchdog only for an accepted `SET`;
- make `STOP` set both targets to zero through the bounded deceleration/coast
  path without disarming; make `DISARM` force zero/coast and require `ARM`
  before later motion;
- ramp a timed-out target to zero and coast; a later valid `SET` may recover;
- latch driver and encoder-stall faults until `RESET_FAULT` is received while
  disarmed, both targets are zero, and the physical fault is absent;
- run wheel PI control at 200 Hz and publish telemetry at 20 Hz;
- use signed encoder counts per second as the wheel target;
- enable raw-duty test commands only in a commissioning build, cap them by the
  active test limit and 95% absolute ceiling, require a duration, and
  automatically coast when the duration expires; and
- make the commissioning utility send `STOP`, request `STATUS`, and confirm
  state before it offers an operator any motion command.

No checksum or sequence layer is required initially. The parser and watchdog
provide the application safety boundary over the ordered USB link. Add another
integrity layer only if measured communication failures justify it.

## Bench, Due, and Encoder Path

### B1 — Inventory and Evidence Baseline

1. Lay out the active non-deferred baseline: Pi/NVMe/HAT/cooler, official Pi
   supply, Due, `#2507`, two `#4753` motors and harnesses, wheels/hubs/caster,
   `#735`, `#2204`, carrier board, `104` capacitor, DROK, BNO055 and `#954`
   cable, owned Adafruit `#2998` USB hub, Camera Module 3 and Standard-to-Mini
   cable, USB-A-to-micro-B cable, one 23 mm 2x20 GPIO extender, 16 AWG wire,
   14 AWG fuse holder/10 A fuse, ALITOVE splices, and intended low-current
   leads.
2. Record exact markings, quantity, visible damage, connector/header state,
   cable ends and approximate lengths, and all required soldering.
3. Confirm the `#2507`, `#735`, `#2204`, and user-reported owned `#2998` are
   the intended products. Keep the `#2991`, optional sensors, toggle, and white
   terminal strips outside the installed baseline.
4. Confirm the battery, mating connector, undervoltage method, and RPLidar are
   absent/deferred rather than inventory failures.

**Pass:** every in-scope item is positively identified or explicitly recorded
as a blocker; no ambiguous substitute is accepted.

**Safe end state:** all parts remain disconnected and unpowered.

### B2 — Bench Test Rig

1. Inspect the C3010 case, terminals, controls, mains lead, fan openings, and
   fuse area. With nothing connected, set current low, enable the output, and
   compare several conservative voltage settings with the multimeter.
2. Mount the three load resistors on the heat-safe base using 16 AWG leads and
   guarded connections. Measure and record each cold resistance.
3. Provide three mutually exclusive load configurations:
   - 10 Ω alone for about 0.5 A at 5.10 V;
   - one 2 Ω resistor alone for about 2.55 A;
   - both 2 Ω resistors in parallel for about 5.1 A.
4. The 10 Ω branch must be disconnected during the 5.1 A configuration;
   otherwise the demand is about 5.6 A.
5. Prove CC operation at a safe low voltage: connect one 2 Ω branch with the
   output disabled, set a 1 A limit, enable, and confirm the supply reduces
   voltage to hold approximately 1 A. Estimate current from measured
   load voltage divided by the recorded resistance.
6. Verify the output-enable control removes voltage. Inspect leads, resistors,
   and supply heating after the short test.
7. Establish fixed IR measurement locations and verify repeatable readings
   against ambient.

**Pass:** voltage readings are stable and credible, CC/CV and output enable
behave correctly, the load fixture has no exposed live conductors or loose
connections, and temperature can be recorded repeatably.

**Safe end state:** output disabled, voltage/current controls turned down, load
fixture disconnected and cooled.

### B3 — Due Toolchain and Safe Boot

1. Install Arduino CLI or IDE plus the Arduino SAM Boards core.
2. Select the Due Programming Port target
   (`arduino:sam:arduino_due_x_dbg`) and use only the Programming USB port.
3. Create the evolving firmware skeleton. Its first startup actions must make
   D6/D7 outputs LOW before direction/control initialization.
4. Compile, upload, reset, disconnect, and reconnect while motor power and
   driver wiring remain absent.
5. Verify the board enumerates and emits a versioned startup/status line.
6. Measure Due 5 V and 3.3 V relative to Due ground.

**Pass:** repeated upload/reset/reconnect succeeds, startup remains disarmed,
and both rails are stable and plausible.

**Safe end state:** Due may remain connected to one USB host; no external
power or loads are connected.

### B4 — Serial Safety Foundation

1. Implement the interface and parsing rules defined above.
2. Add an explicit state machine for disarmed, armed, watchdog stop, and
   latched fault.
3. Exercise valid commands, blank lines, overlong lines, missing/extra tokens,
   non-numeric targets, and out-of-range targets with motor power absent.
4. Send valid `SET` lines at 20 Hz, stop transmission, and record the watchdog
   transition after 500 ms.
5. Confirm malformed input never arms motion or refreshes the watchdog.
6. Add the Python commissioning utility and make it log timestamped telemetry
   to CSV without requiring ROS.

**Pass:** parser and state-machine tests match the interface, and loss of valid
commands reliably produces the zero-target/coast state.

### B5 — PWM Commissioning

1. Configure D6 and D7 from the Due hardware PWM peripheral at 20 kHz.
2. With all driver and motor wiring absent, connect D6 to temporary capture
   input D3 and measure period and high time using the separate timer channel.
3. Check several duties including 0%, a low commissioning value, 50%, and the
   95% ceiling. Repeat with D7 connected to D3.
4. Verify reset and disarm drive each PWM output LOW.
5. Remove the D3 loopback after testing.

**Pass:** both outputs report approximately 20 kHz, measured duty follows the
command within one percentage point, and all safe states produce LOW.

**Limitation:** this is same-controller commissioning evidence, not an
independent oscilloscope calibration. Record that limitation in the log.

### B6 — Encoder Translator Assembly

1. Inspect the owned Mega Prototype Shield V3 and confirm it provides suitable
   0.1-inch construction with no unexpected pre-connected rail pattern. Use a
   small solderable perfboard only if this inspection fails.
2. Mark socket pin 1 and install the `#2204` so the `#735` remains removable.
3. Wire the translator exactly as listed in the interface matrix:
   `DIR` to 3.3 V, `/OE` to ground, VCC to 3.3 V, ground to common logic
   ground, A1–A4 as inputs, B1–B4 as outputs, A5–A8 grounded, and B5–B8 open.
4. Mount the `104` capacitor directly across pins 20 and 10.
5. If retaining each motor's 1x6 encoder housing, cut two marked 1x6 male
   segments from the unused portion of the `#2507`-supplied 0.1-inch
   breakaway header and solder them to the carrier. Verify the actual motor
   housing cavity order and orientation before mating either connector. Leave
   the two positions corresponding to the removed/cut motor leads electrically
   unconnected and insulate any abandoned contact stubs.
6. Before inserting the translator, continuity-check every intended net and
   inspect for solder bridges, reversed socket orientation, or connected
   unused outputs.
7. Verify the future 5 V encoder rail is isolated from 3.3 V and all B-side/Due
   nets.

**Pass:** the unpowered carrier matches the fixed-wiring table with no
unintended continuity.

### B7 — Encoder Translator Powered Test

1. Insert the `#735` with power absent and confirm orientation.
2. Connect only Due USB, common ground, Due 3.3 V to translator VCC/control,
   and Due 5 V to one encoder supply.
3. Measure 3.3 V at translator VCC and 5 V at encoder blue/green.
4. Turn the encoder by hand and verify A-side signals switch between about
   0 V and 5 V while corresponding B-side signals remain between about
   0 V and 3.3 V.
5. Confirm no Due input is exposed to 5 V before connecting B1–B4 to the Due.

**Pass:** supplies and translated levels are correct and stable with no
cross-rail connection.

### B8 — Left Encoder Hand Test

1. Connect left A/B through B1/B2 to Due D2/D13.
2. Mark the output shaft or attached hub and zero the count.
3. Turn one full revolution slowly in each direction.
4. Record sign and count. Reverse rotation should reverse sign and return near
   the starting count.
5. Repeat several times while moving the harness gently to expose intermittent
   contacts.

**Pass:** each revolution produces 3200 quadrature counts, direction is
consistent, and no intermittent jumps or missing counts appear.

### B9 — Right Encoder Hand Test

Repeat B8 with right A/B through B3/B4 to Due D5/D4 while monitoring both
counters.

**Pass:** the right encoder meets the same count/direction criteria and neither
encoder produces activity on the other counter.

## Driver and Drivetrain

### B10 — Motor-Driver Assembly

1. With the board unpowered, inspect `#2507` markings, PCB damage, mounting
   holes, and included connectors.
2. Solder the three 2-pin terminal blocks and one 13-pin logic-header section.
   Do not install stackable headers or `ARDVIN=VOUT`.
3. Inspect all 19 joints and clean residue if required.
4. Continuity-check each terminal/header to its intended pad and check for
   adjacent bridges.
5. Verify VIN is not shorted to ground and motor outputs are not shorted to
   logic rails. Account for semiconductor/capacitor charging behavior rather
   than treating every momentary meter indication as a short.

**Pass:** the board is mechanically secure and matches the approved
general-purpose configuration.

### B11 — Motor-Driver Logic Test

1. Keep driver VIN and both motors disconnected.
2. With owned male-to-female Dupont leads, put male ends in the Due sockets and
   female ends on the `#2507` male header. Connect Due 3.3 V to `VDD`, join
   logic grounds, and connect D6–D11, D22/D23, and A0/A1 according to the
   matrix; twelve conductors are required in total.
3. Boot disarmed and verify D6/D7 remain LOW while direction lines follow only
   permitted test commands.
4. Record A0/A1 zero readings using 12-bit ADC mode.
5. Observe EN/DIAG with VIN absent. A disabled/fault indication is permitted
   because the driver motor supply is missing; do not require the powered
   normal state at this gate.

**Pass:** the Due remains stable, reset-safe PWM is preserved, ADC readings
are plausible, and no logic line exceeds 3.3 V.

### B12 — First Powered Motor Channel

1. Secure M1 with its wheel clear. Land its factory red/black motor leads
   directly in M1A/M1B.
2. Connect the C3010 to driver VIN/GND with adequate wire and common logic
   reference. Start near 7–8 V and a 0.5–1 A limit.
3. Enable motor power while firmware is disarmed. Verify EN/DIAG indicates the
   powered normal state and the motor remains stopped/coasting.
4. Arm and apply a low, time-bounded duty in one direction, stop, then repeat
   in the other direction.
5. Establish and record which polarity is positive for M1 and make encoder sign
   agree with that convention.
6. Compare A0-derived current using the nominal 0.140 V/A relationship with
   the supply display. Treat this as a plausibility check under PWM, not a
   precision calibration.
7. Test commanded coast and output disable before raising voltage or duty.

**Pass:** M1 turns smoothly both ways, direction/count sign agree, current
telemetry is plausible, and stop/disarm/reset produce coast without a reset or
fault.

### B13 — First Closed-Loop and Safety Test

1. Implement a 200 Hz PI wheel-speed loop using encoder counts. Start at low
   target rates and conservative duty/ramp limits.
2. Tune M1 for stable response without sustained oscillation or current near
   the continuous target while unloaded.
3. With the wheel raised, test boot, Due reset, firmware upload, serial
   disconnect, watchdog stop, reconnect, and recovery.
4. Simulate driver disable/fault by pulling M1 EN/DIAG low through 1 kΩ using a
   controlled temporary connection. Verify both targets coast and motion
   latches off. Remove the connection before `RESET_FAULT`.
5. To test missing-encoder response, power down, disconnect only the encoder
   signal path, restore power, and issue a low target. Verify the motor is
   coasted after the configured grace/detection interval. Power down before
   reconnecting the encoder.

**Pass:** closed-loop speed is stable and every safety transition matches the
selected recoverable-versus-latched policy without a mechanical stall.

### B14 — Modular Drivetrain Deck

1. Measure both accepted motors, hubs, wheels, caster, fasteners, and cable
   exit envelopes.
2. CAD a reusable deck with both motor mounts, caster mount, wheel clearance,
   temporary driver/Due mounting, a modular hole pattern, and tie points for
   both motor-power and USB tethers.
3. Print and inspect the deck before installing electronics.
4. Mount both motors, wheels, and caster; apply required threadlocker only
   where specified by the fastener/component instructions.
5. Verify free wheel rotation, ground clearance, fastener engagement, cable
   clearance, and strain relief.
6. Record physical wheel-center separation, nominal wheel radius, caster
   position, deck envelope, and assembled deck mass.

**Pass:** the deck rolls freely, nothing rubs or loosens, and the measured
geometry is recorded for later CAD/software synchronization.

### B15 — Second Powered Motor Channel

Mount/connect M2 and repeat B12 independently using M2, D7, D10/D11, D23, A1,
and the right encoder.

**Pass:** M2 meets the accepted M1 direction, current, coast, and reset
criteria with its own polarity recorded.

### B16 — Raised Two-Channel Test

1. Raise and secure both wheels.
2. Command each channel alone in both directions while monitoring both encoder
   counters and current channels.
3. Command matched and deliberately unmatched targets.
4. Repeat simultaneous start/stop and direction changes within conservative
   acceleration limits.
5. Monitor supply voltage, Due resets, USB behavior, encoder integrity, and
   EN/DIAG.

**Pass:** both channels remain independent, simultaneous operation is stable,
and no electrical-noise-induced count, fault, USB, or reset problem appears.

### B17 — Two-Channel PI Tuning

1. Apply one shared PI baseline to both channels.
2. Record steady rate, error, current, and transient behavior at several
   conservative forward/reverse targets.
3. Keep shared gains if both channels meet the same stability/tracking
   criteria. Add channel-specific values only when repeatable evidence shows
   the shared values cannot meet them.
4. Confirm the 95% absolute duty ceiling remains enforced.

**Pass:** both raised wheels track commanded rates without sustained
oscillation and the reason for shared or separate values is documented.

### B18 — Low-Speed Floor Commissioning

1. Choose a clear level lane and keep the Pi out of the control path. Use the
   commissioning computer, Due USB, and current-limited motor supply.
2. Secure both tethers to the deck so connector contacts cannot take a pull.
   One operator stays at the supply/output control and manages slack.
3. Begin well below 0.15 m/s with short forward, coast, and reverse commands.
4. Increase only after straight motion, direction, current, cable behavior,
   and stopping are predictable.
5. Tune acceleration, controlled deceleration, near-zero coast transition,
   stall arming command, startup grace, minimum encoder progress, and detection
   interval.
6. Do not use stationary pivots or a mechanical stall to tune protection.

**Pass:** the deck performs repeatable short shuttles without slip, oscillation,
cable loading, unexpected fault, or unsafe stopping.

## Pi, Peripherals, and Power

### B19 — Pi-to-Due Integration

1. Power the Pi from the official 27 W USB-C supply.
2. Disconnect any development-computer USB host from the Due, then connect one
   Pi USB-A port to the Due Programming port with the data-capable cable.
3. Run the commissioning utility from the Pi and log status/telemetry.
4. Exercise Pi-first and Due-first availability, Pi reboot, USB disconnect,
   reconnect, Due reset, and firmware upload.
5. Verify no stale command causes motion after any transition.

**Pass:** command and telemetry remain reliable, only one USB host powers the
Due, and every interruption produces the selected safe state.

### B20 — BNO055 Acceptance

1. With the Pi on official USB-C power, inspect/solder the BNO055 header if
   required.
2. Plug the owned `#2998` captive USB-A lead into one black Pi USB 2.0 port.
   Leave its 1.35 mm external-power jack empty, select and mark hub port 1,
   and keep the hub's single downstream-power switch on.
3. Plug the USB end of `#954` into hub port 1. Connect `#954` red to `VIN`,
   black to ground, white/RX to BNO SDA/TX, and green/TX to BNO SCL/RX. Strap
   BNO `3VO` to `PS1` with one owned female-to-female jumper; leave `PS0` at
   default.
4. Do not connect STEMMA I2C simultaneously.
5. Verify hub and `#954` enumeration, switch off/on recovery, UART
   communication at 115200 baud, self-test/system
   status, plausible stationary readings, and expected axis response when the
   board is turned by hand.
6. Measure observed update behavior without claiming final latency,
   calibration, or fusion suitability.

**Pass:** UART data and status are stable and the future mounting orientation
is documented. Navigation fusion remains deferred.

### B21 — Camera Acceptance

1. Power down the Pi before handling the FFC.
2. Verify the narrow 22-pin end goes to the Pi and the wider 15-pin end to the
   camera with contact orientation matching the connectors.
3. Boot on official USB-C power, verify camera detection, and stream a test
   image.
4. Confirm the intended forward/up orientation and cable bend/service
   envelope for CAD.

**Pass:** detection and streaming are repeatable with no FFC damage or
intermittent connection.

### B22 — DROK and Dummy-Load Acceptance

1. Record the exact DROK markings, terminal labels, adjustment type, physical
   condition, and whether input/output grounds are common.
2. Build the intended four-lead output harness using two equal short positive
   leads and two equal short grounds. Terminate them on a secured 2.54 mm
   header fixture representing Pi pins 2/4 and 6/14; do not use the Pi as the
   dummy-load connector.
3. Feed the DROK from the C3010 at a representative 3S voltage with a
   conservative current limit. With no output load, adjust to 5.10 V using the
   multimeter at the harness end.
4. Disable output, power-cycle repeatedly, and verify the same stable setting.
   Record that fast startup transients remain outside ordinary multimeter
   bandwidth unless the meter provides a suitable capture mode.
5. With output disabled between every reconfiguration, test:
   - 10 Ω alone for about 0.5 A;
   - one 2 Ω branch alone for about 2.55 A;
   - both 2 Ω branches in parallel for about 5.1 A, with 10 Ω disconnected.
6. At each level record converter input/output voltage, voltage at the harness
   end, calculated load current, and IR temperatures at fixed converter,
   connector, and resistor locations.
7. Hold the final load long enough to establish regulation and a credible
   temperature trend, up to 30 minutes. Stop for instability or continued
   unsafe heating.
8. Let the fixture cool, then secure/cover the DROK adjustment. Never adjust
   it later with the Pi connected.

**Pass:** the complete output harness sustains each load with correct polarity,
stable voltage, acceptable drop, no loose/hot contact, and no progressive
converter failure. Ordinary-meter bandwidth limitations are recorded rather
than hidden.

### B23 — Pi Header Power and Combined Load

1. Power everything down and remove Pi USB-C.
2. Continuity- and polarity-check the four-lead harness at the Pi connector
   before installation. Confirm one owned 23 mm 2x20 extension exposes the
   correct pins through the actual M.2 HAT+ stack and that the jumper ends mate
   securely. Connect positives to physical pins 2/4 and grounds to 6/14.
3. Feed the DROK through the 10 A fuse and selected 16 AWG/ALITOVE
   distribution from the C3010. Leave the motor branch disabled initially.
4. Enable power and exercise Pi boot, NVMe, Active Cooler, CPU load, Due,
   `#2998`/BNO055, and camera. Monitor Pi undervoltage/USB warnings, resets,
   hub enumeration/recovery, harness-end voltage, and connection temperatures.
5. Enable the motor branch and repeat during simultaneous raised-wheel starts
   and operation.
6. Enable `PSU_MAX_CURRENT=5000` only after the complete path passes, then
   verify the Pi reports the intended high-current mode.

**Pass:** no polarity error, undervoltage, unstable output, excessive drop,
heating, USB fault, or Pi/Due reset occurs under combined operation.

## Final Integration and Gate Closure

### B24 — Final Electronics-Tier CAD

1. Use measured component envelopes and accepted connection directions rather
   than catalog-only dimensions.
2. Provide service access to Pi, Due Programming USB/reset, `#2507` terminals,
   fuse, DROK adjustment cover, `#2998` switch/ports, BNO055, camera connector,
   and wire clamps.
3. Preserve Pi/NVMe/cooler airflow and separate motor/source-current routing
   from encoder and logic wiring.
4. Define and mark the BNO055 orientation and camera view.
5. Reserve noncommittal envelopes and mounting options for the deferred
   battery and RPLidar without selecting either component.
6. Review the CAD against the matrix before printing.

**Pass:** every installed component, connector, cooling path, and strain-relief
point is accounted for without assuming deferred hardware.

### B25 — Final Mechanical and Wiring Build

1. Print and inspect the electronics tier; reject warped, cracked, obstructed,
   or weak mounting features.
2. Mount the Pi/NVMe/cooler, Due, driver, translator carrier, DROK, `#2998`,
   BNO055, and camera with serviceable fasteners and electrical clearance.
3. Build the tethered harness from the interface matrix:
   bench source input to 10 A fuse and ALITOVE distribution, one 16 AWG branch
   to driver VIN, and one 16 AWG branch to DROK.
4. Keep the bench-source input removable because the battery connector remains
   deferred.
5. Route and secure logic, encoder, USB, camera, and UART leads. Keep the Due
   direct to one black Pi USB port, the `#2998` on the other black port with
   `#954` on marked hub port 1, and its external-power jack empty. No loose
   breadboard connection is allowed in the integrated build.
6. With all sources absent, verify ALITOVE topology, DROK ground relationship,
   fuse continuity, polarity, every point-to-point net, and absence of
   cross-rail shorts.
7. Tug-test every termination individually.

**Pass:** mechanical access and routing match CAD, every installed interface
matches the matrix, and the complete unpowered build passes inspection.

### B26 — Integrated Raised Regression

1. Raise and secure both wheels.
2. Apply power in the documented order and verify disarmed/coast startup.
3. Repeat all safety transitions: reset, upload, valid-command loss,
   recoverable watchdog, simulated driver fault, and missing-encoder stall.
4. Exercise both speed loops forward/reverse and simultaneous start/stop.
5. Monitor encoder integrity, current/fault telemetry, Pi/Due resets,
   undervoltage, direct USB and hub stability, BNO055 updates, camera stream,
   and connection temperatures.
6. Repeat multiple cold starts and orderly shutdowns.

**Pass:** the integrated build preserves every subsystem acceptance result and
introduces no reset, noise, thermal, wiring, or peripheral regression.

### B27 — Loaded Thermal Shuttle

1. Measure and record the actual complete Stage 2 mass. Do not add speculative
   battery/LiDAR ballast.
2. Use a clear, level lane with strain-relieved power leads, an operator
   managing slack, and immediate access to supply output disable.
3. Use approximately 0.15 m/s and repeat:
   - about 0.75 m forward;
   - five seconds coast;
   - about 0.75 m reverse;
   - five seconds coast.
4. Include occasional gentle differential-speed arcs; do not perform repeated
   stationary pivots.
5. Every five minutes record ambient, both motor-case temperatures, both
   driver-area temperatures, supply/harness voltage, per-channel current
   telemetry, faults, resets, and observed performance.
6. Run 30 minutes, then extend in 10-minute blocks up to 60 minutes until
   temperature rise is no more than 2 °C across the final 10 minutes.
7. Stop for cable snagging, looseness, odor/smoke, unexpected noise,
   fault/reset, Pi undervoltage, normal loaded current inconsistent with the
   1.38 A-per-motor target, continued temperature rise, or progressive
   performance loss.

**Pass:** normal loaded current remains consistent with the design target,
temperatures approach the defined stable trend, and no electrical, mechanical,
software, or connection failure occurs.

### B28 — Close the Hardware Gate

1. Transfer accepted polarity, PI, current, acceleration, coast, watchdog, and
   stall values into the tracked firmware configuration.
2. Export accepted chassis/tier STEP and STL files into `hardware/cad/`; keep
   SolidWorks sources in Google Drive according to project policy.
3. Measure the final wheel-center separation, nominal wheel radius, chassis
   envelope, and mass. Update the URDF and controller configuration from those
   values; leave empirical effective-radius/separation correction to Stage 3
   odometry calibration.
4. Expand both default and `use_ros2_control:=true` xacro paths and rebuild the
   ROS package.
5. Review every Stage 2A Q1–Q11 decision against the completed log. Update the
   architecture/matrix only for evidence-driven changes.
6. Confirm every B1–B28 log entry is complete and approved before marking the
   architecture bench validated.

**Pass:** firmware, CAD exports, software geometry, architecture, matrix,
phase tracker, and validation evidence all describe the same accepted robot.

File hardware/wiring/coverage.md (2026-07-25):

# Wiring Diagram Coverage

This ledger cross-checks the WireViz diagrams against the authoritative
[power and signal interface matrix](../power-signal-interface-matrix.md).
Coverage means the intended relationship is shown; it does not mean that the
connection has passed electrical or as-built validation.

## Power Interfaces

| ID | Connection | WireViz coverage |
|---|---|---|
| P0 | Official 27 W USB-C supply to Pi, bench alternative | `pi/pi-wiring.yml` |
| P1 | Future 3S battery, keyed connector, fuse, and distribution | `power/main-power-path.yml` |
| P2 | Distribution to `#2507` VIN/GND | `power/main-power-path.yml` |
| P3 | `#2507` M1 output to left motor conductors | `motor-encoder/motor-wire-groups.yml` |
| P4 | `#2507` M2 output to right motor conductors | `motor-encoder/motor-wire-groups.yml` |
| P5 | Distribution to DROK input | `power/main-power-path.yml` |
| P6 | DROK output through owned 23 mm stacking header to Pi pins 2/4/6/14 | `power/main-power-path.yml`, `pi/pi-wiring.yml` |
| P7 | Pi USB-A to Due Programming port | `power/main-power-path.yml`, `pi/pi-wiring.yml` |
| P8 | Due 5 V/GND to both encoders | `motor-encoder/motor-wire-groups.yml`, `control-logic/control-logic.yml`, `control-logic/encoder-translator.yml` |
| P9 | Due 3.3 V/GND to `#2507` VDD and translator | `control-logic/control-logic.yml`, `control-logic/due-motor-driver.yml`, `control-logic/encoder-translator.yml` |
| P10 | Pi through owned Adafruit `#2998` hub and `#954` to BNO055 power | `pi/pi-wiring.yml` |
| P11 | Pi CAM/DISP to Camera Module 3 | `pi/pi-wiring.yml` |
| P12 | Pi USB to future RPLidar development-kit adapter | `pi/pi-wiring.yml` |

## Signal Interfaces

| ID | Connection | WireViz coverage |
|---|---|---|
| S1 | Pi USB serial link to/from Due | `pi/pi-wiring.yml` |
| S2 | Due D6/D7 to M1PWM/M2PWM | `control-logic/control-logic.yml`, `control-logic/due-motor-driver.yml` |
| S3 | Due D8-D11 to driver direction inputs | `control-logic/control-logic.yml`, `control-logic/due-motor-driver.yml` |
| S4 | Driver M1EN/DIAG and M2EN/DIAG to Due D22/D23 | `control-logic/control-logic.yml`, `control-logic/due-motor-driver.yml` |
| S5 | Driver M1CS/M2CS to Due A0/A1 | `control-logic/control-logic.yml`, `control-logic/due-motor-driver.yml` |
| S6 | Both encoder A/B outputs to translator A1-A4 | `motor-encoder/motor-wire-groups.yml`, `control-logic/control-logic.yml`, `control-logic/encoder-translator.yml` |
| S7 | Translator B1-B4 to Due D2/D13/D5/D4 | `control-logic/control-logic.yml`, `control-logic/encoder-translator.yml` |
| S8 | BNO055 UART through active Adafruit `#954` and the `#2998` USB hub | `pi/pi-wiring.yml` |
| S9 | BNO055 3VO-to-PS1 UART-mode strap | `pi/pi-wiring.yml` |
| S10 | Camera Module 3 CSI/control interface | `pi/pi-wiring.yml` |
| S11 | Future RPLidar USB link | `pi/pi-wiring.yml` |

## Translator Fixed Wiring

| Requirement | WireViz coverage |
|---|---|
| Pin 1 DIR to Due 3.3 V | `control-logic/control-logic.yml`, `control-logic/encoder-translator.yml` |
| Pins 2-5 A1-A4 from left/right encoders | Same |
| Pins 6-9 A5-A8 to logic ground | Same |
| Pin 10 to common logic ground | Same |
| Pins 11-14 B8-B5 left unconnected | Same; the open pins are visible and labeled |
| Pins 15-18 B4-B1 to Due D4/D5/D13/D2 | Same |
| Pin 19 `/OE` to logic ground | Same |
| Pin 20 VCC to Due 3.3 V | Same |
| `104` / 0.1 uF capacitor across pins 20 and 10 | Same |

## System Rules Represented

- High-current battery negative, driver power ground, and DROK input return are
  shown in `power/main-power-path.yml`.
- Due logic ground is joined to the driver logic reference, translator,
  and both encoders in the control-logic diagrams. Notes explicitly prohibit
  motor return current from using these low-current paths.
- Pi USB-C bench power and DROK header power are shown as mutually exclusive in
  `pi/pi-wiring.yml`.
- The Due has one powered USB host, the Pi, in `pi/pi-wiring.yml`.
- The Due stays on a direct black Pi USB 2.0 port. Only the low-current
  BNO055/`#954` branch uses the bus-powered `#2998`; its single switch must
  remain on during operation and its external-power jack stays unused.
- Driver PWM startup LOW, fault-input direction, current-sense protection,
  translator direction/enable straps, and open translator pins are labeled in
  the control-logic diagrams.

## Installed Pi Assemblies Outside the P/S Matrix

The Pi diagram also shows the already-installed Active Cooler with its supplied
fan lead, the M.2 HAT+ with its supplied PCIe FFC, and the NVMe M.2 edge
connection. These are treated as complete managed assemblies rather than
field-wired individual conductors. A STEMMA QT lead must not replace the fan
lead merely because both connectors are small four-pin types.

## Owned Wiring and Connector Disposition

| Owned BOM item | Diagram assignment |
|---|---|
| 16 AWG silicone wire | P1 trunk/fused segment, P2 driver branch, and P5 DROK input branch in `power/main-power-path.yml` |
| Waterproof inline holder plus one 10 A fuse from the standard kit | F1 in `power/main-power-path.yml` |
| ALITOVE 3-wire splice pieces | Separate fused-positive and battery-negative 3-way junctions in `power/main-power-path.yml`, but only after continuity proves the selected ports are common |
| 23 mm 2x20 extra-tall stacking header | One H1 GPIO extension through the M.2 HAT+ in both power and Pi views |
| Assorted Elegoo/Dupont leads | Four short P6 power leads; twelve male-to-female Due/`#2507` logic leads; low-current carrier wiring; one BNO055 mode strap |
| Two `#4753` factory 1x6/2.54 mm harnesses | Motor, encoder-power, and encoder-signal groups in `motor-encoder/` and `control-logic/` |
| `#2507` supplied screw terminals and breakaway male header | Power/motor terminations, the 13-pin logic header, and optionally two marked 1x6 carrier headers for the retained encoder housings |
| Mega Prototype Shield V3, `#2204`, `#735`, and `104` capacitor | Socketed encoder-translator carrier in both translator diagrams |
| Adafruit `#954` and user-reported owned `#2998` | BNO055 UART cable and bus-powered USB expansion in `pi/pi-wiring.yml` |
| Owned camera FFC, cooler lead, and M.2/PCIe parts | Used intact as the complete managed assemblies shown in `pi/pi-wiring.yml` |
| 5-pin Pololu `#5530`/`#5534` JST-SH cables | Spare: no installed endpoint has a matching 5-pin/1 mm socket |
| 4-pin STEMMA QT cables | Spare for future I2C experiments; not used with the selected BNO055 UART connection |
| Weewooday terminal strips | Optional secured bench fixtures only; not part of the mobile battery or motor path |

## Explicitly Provisional or Non-Installed

- The battery, keyed connector family, and battery-specific undervoltage
  solution remain unselected; the provisional path is shown and labeled.
- Motor connector cavity order and final motor terminal polarity require
  physical inspection and the unloaded direction test.
- Exact top/bottom member of each same-color Pi USB pair, CAM/DISP port,
  `#2998` socket label/captive-lead length, cable lengths, and several
  low-current termination/fanout details remain to be marked after placement.
- The future RPLidar connection is shown but is not an installed component.
- INA219, APDS9960, HC-SR04, `#2991`, white terminal strips, and the 1 A toggle
  remain outside the installed baseline.
- The temporary D6/D7-to-D3 PWM commissioning loop is not an installed
  connection. It is deliberately absent from the as-built diagrams and must be
  removed after its test.

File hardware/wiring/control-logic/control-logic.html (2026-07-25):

# Due, motor-driver, and encoder control logic

## Diagram

Complete installed control and feedback wiring among the Arduino Due, Pololu #2507, both #4753 encoders, and 74LVC245 translator.

This diagram covers P8, P9, and S2 through S7.
Use the owned Mega Prototype Shield V3 as the translator carrier, one #2204 socket, one #735, and owned Elegoo/Dupont leads.
Logic jumper colors and installed lengths are not yet assigned, so non-factory conductors render neutrally.
Encoder outputs are 5 V on the translator A side and must never connect directly to the 3.3 V-only Due.
Driver B motor terminals are not logic ground; motor power wiring is documented separately.

## Bill of Materials

Id | Description | Qty | Unit | Designators
1 | Connector, Arduino Due, Installed power, control, and feedback pins, 17 pins | 1 | | DUE1
2 | Connector, Owned 0.1 uF ceramic capacitor, 104 decoupling capacitor, 2 pins | 1 | | C1
3 | Connector, Owned Adafruit #735 74LVC245 octal bus transceiver, 3.3V encoder level translator in #2204 socket on Mega prototype carrier, 20 pins | 1 | | U1
4 | Connector, Pololu #2507 Dual VNH5019 motor driver, Logic header, 12 pins | 1 | | DRV1
5 | Owned Adafruit #2204 20-pin IC socket | 1 | | U1
6 | Owned Arduino Mega Prototype Shield V3, Translator and encoder fanout carrier | 1 | | U1

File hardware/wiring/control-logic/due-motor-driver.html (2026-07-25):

# Arduino Due and motor-driver logic

## Diagram

Focused P9 and S2-S5 wiring between the Arduino Due and Pololu #2507 logic header.

This focused view is intentionally redundant with control-logic.yml.
Use twelve owned Elegoo male-to-female Dupont leads: male at the Due sockets and female at the #2507 header.
Jumper colors and installed lengths remain unassigned.
Motor supply and motor-output conductors are documented in the power and motor-encoder folders.

## Bill of Materials

Id | Description | Qty | Unit | Designators
1 | Connector, Arduino Due, Motor-control pins, 12 pins | 1 | | DUE1
2 | Connector, Pololu #2507 Dual VNH5019 motor driver, Logic header, 12 pins | 1 | | DRV1

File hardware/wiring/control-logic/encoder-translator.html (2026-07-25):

# Encoder translator and Arduino Due wiring

## Diagram

Focused P8, P9, S6, and S7 wiring for both #4753 encoders, the 74LVC245, and Arduino Due.

This focused view is intentionally redundant with control-logic.yml and motor-wire-groups.yml.
Use the owned Mega Prototype Shield V3 as carrier, one #2204 socket, one #735 translator,
two marked 1x6 header segments for the factory encoder housings, and owned low-current jumper wire.
The complete 74LVC245 DIP pinout is shown, including grounded unused A inputs,
open unused B outputs, fixed DIR and /OE straps, and local decoupling.

## Bill of Materials

Id | Description | Qty | Unit | Designators
1 | Connector, Arduino Due, Encoder interface pins, 7 pins | 1 | | DUE1
2 | Connector, Owned 0.1 uF ceramic capacitor, 104 decoupling capacitor, 2 pins | 1 | | C1
3 | Connector, Owned Adafruit #735 74LVC245 octal bus transceiver, 3.3V translator in #2204 socket on Mega prototype carrier, 20 pins | 1 | | U1
4 | Owned Adafruit #2204 20-pin IC socket | 1 | | U1
5 | Owned Arduino Mega Prototype Shield V3, Translator and encoder fanout carrier | 1 | | U1

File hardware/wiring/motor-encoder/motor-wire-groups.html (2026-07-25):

# Diff-drive robot motor and encoder wire groups

## Diagram

Both Pololu #4753 six-wire assemblies and their motor-power, encoder-power, and encoder-signal destinations.

Each #4753 motor and encoder is one physical six-wire assembly.
Use the owned factory 20 cm cable; the 1x6 housing is 2.54 mm pitch, not JST-SH.
Wire colors identify the factory leads; shared-housing cavity numbers and order are not yet verified.
Red-to-A and black-to-B are the initial motor-terminal assignments only.
The unloaded direction test determines whether either motor pair must be reversed.

## Bill of Materials

Id | Description | Qty | Unit | Designators
1 | Connector, Adafruit #735 74LVC245 encoder level translator, Encoder-side A inputs, 4 pins | 1 | | U1
2 | Connector, Arduino Due, Encoder power rails, 2 pins | 1 | | DUE1
3 | Connector, Pololu Dual VNH5019 motor driver, #2507 motor-output terminals, 4 pins | 1 | | DRV1

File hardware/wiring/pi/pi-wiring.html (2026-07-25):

# Raspberry Pi 5 power and peripheral wiring

## Diagram

Pi-centered wiring for power, installed storage/cooling, Arduino Due, switched USB hub, BNO055, camera, and future RPLidar.

The DROK header feed is the mobile power method.
The official 27 W USB-C supply is the alternate bench power method.
Never connect the mobile header feed and USB-C power at the same time.
Keep the Due direct on one black USB 2.0 port; put only the low-current BNO055 branch on the owned #2998 hub.
Keep the future RPLidar direct on a blue USB 3.0 port. Exact top/bottom member of each same-color pair and CAM/DISP socket remain to be labeled.

## Bill of Materials

Id | Description | Qty | Unit | Designators
1 | Connector, Adafruit BNO055, UART-mode breakout, 6 pins | 1 | | BNO1
2 | Connector, Arduino Due, Programming micro-USB port, 4 pins | 1 | | DUE1
3 | Connector, DROK 5.10 V converter, 2 pins | 1 | | PS1
4 | Connector, Owned 2x20 extra-tall female 0.1-inch stacking header, 23 mm GPIO extension; four used contacts shown, 4 pins | 1 | | H1
5 | Connector, Owned Adafruit #2998 USB Mini Hub with Power Switch, Bus-powered 4-port USB 2.0 hub with captive USB-A upstream lead, 12 pins | 1 | | HUB1
6 | Connector, Raspberry Pi 5, Power and external interfaces, 22 pins | 1 | | PI1

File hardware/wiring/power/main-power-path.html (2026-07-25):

# Diff-drive robot main power path

## Diagram

Battery through protected distribution, motor-driver and Pi branches, and Pi-to-Due USB.

Design definition only; these connections are not yet electrically validated.
P1 battery connector and undervoltage protection remain battery-selection dependent.
Owned 16 AWG wire, fuse parts, ALITOVE splices, Pi header extender, and jumper leads are assigned below.
Cable lengths are intentionally omitted until physical component placement is known.

## Bill of Materials

Id | Description | Qty | Unit | Designators
1 | Connector, Arduino Due, Programming micro-USB port, 4 pins | 1 | | DUE1
2 | Connector, DROK 5.10 V converter, 4 pins | 1 | | PS1
3 | Connector, Owned 2x20 extra-tall female 0.1-inch stacking header, 23 mm Pi GPIO extension; four used contacts shown, 4 pins | 1 | | H1
4 | Connector, Owned ALITOVE 3-wire splice connector, Battery-negative distribution, 3 pins | 1 | | TB1_NEG
5 | Connector, Owned ALITOVE 3-wire splice connector, Fused-positive distribution, 3 pins | 1 | | TB1_POS
6 | Connector, Owned waterproof medium inline fuse holder, 14 AWG / standard ATO-ATC / 10 A fuse, 2 pins | 1 | | F1
7 | Connector, Pololu Dual VNH5019 motor driver, #2507 power terminal, 2 pins | 1 | | DRV1
8 | Connector, Raspberry Pi 5, Power header below H1 and direct USB-A host port, 8 pins | 1 | | PI1
9 | Owned standard blade fuse from 80-piece kit, 10 A ATO/ATC | 1 | | F1

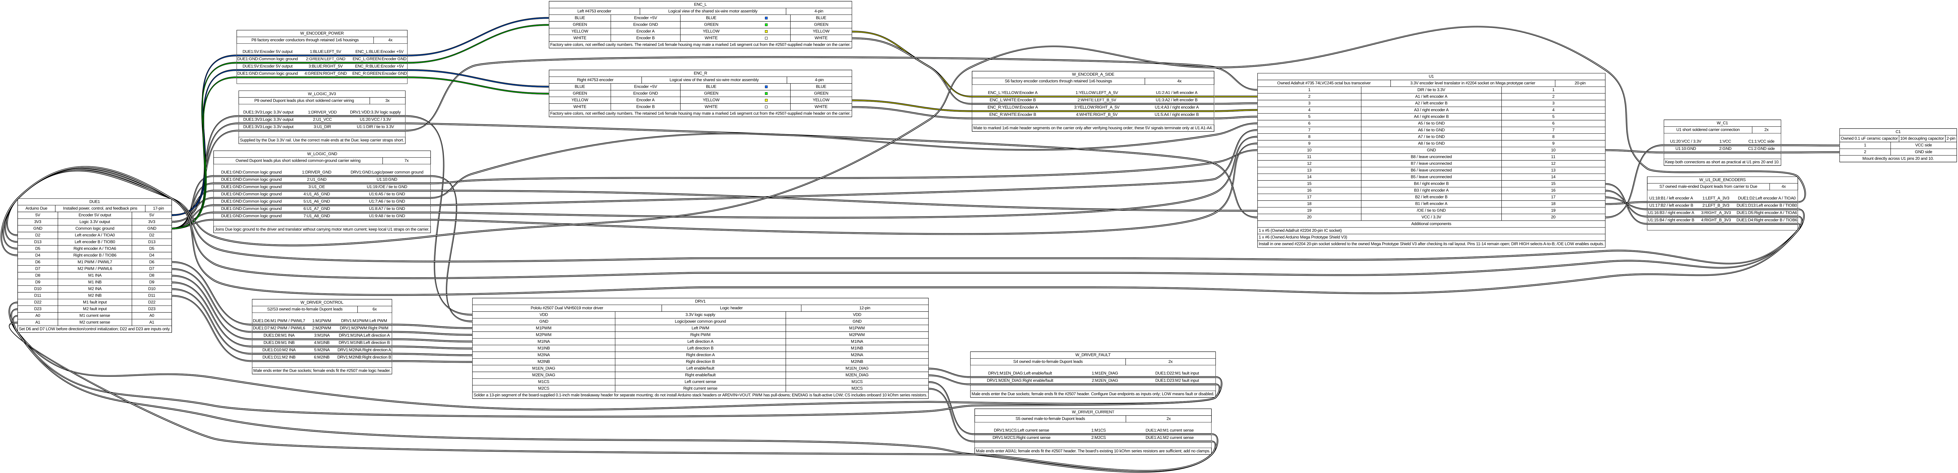
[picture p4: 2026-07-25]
hardware/wiring/control-logic/control-logic.png

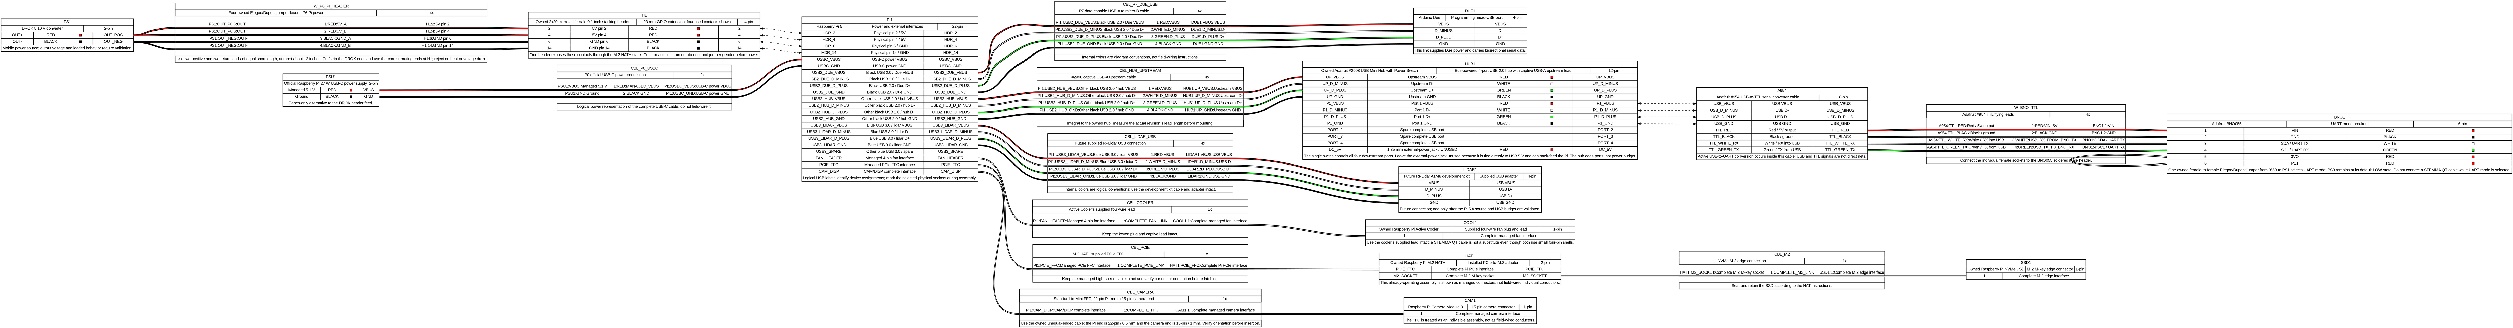
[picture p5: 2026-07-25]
hardware/wiring/pi/pi-wiring.png

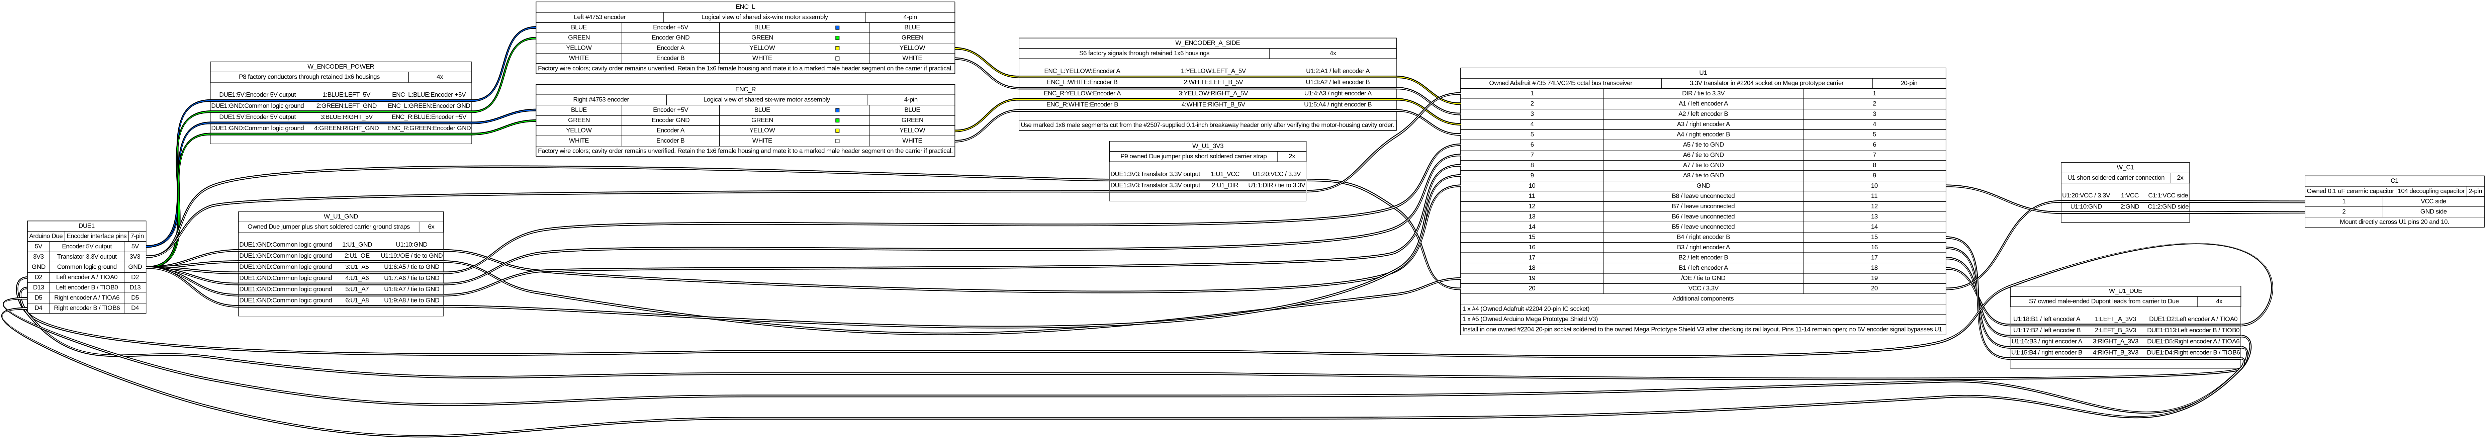
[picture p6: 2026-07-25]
hardware/wiring/control-logic/encoder-translator.png

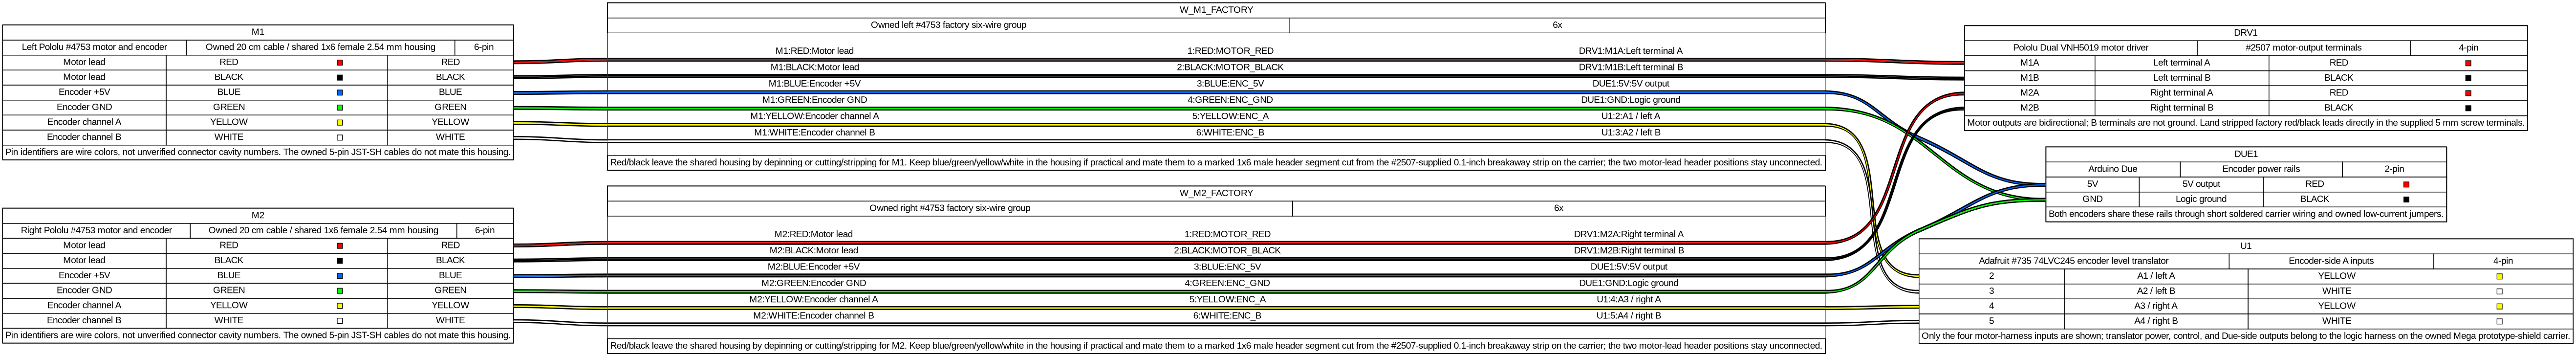
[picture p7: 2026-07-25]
hardware/wiring/motor-encoder/motor-wire-groups.png

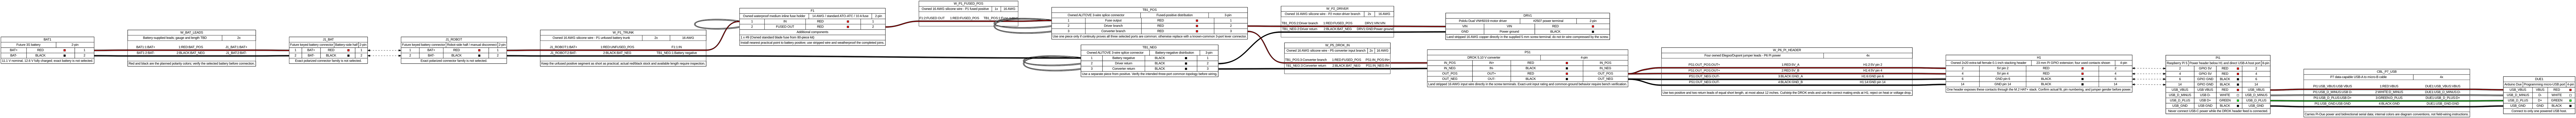
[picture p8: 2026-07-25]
hardware/wiring/power/main-power-path.png

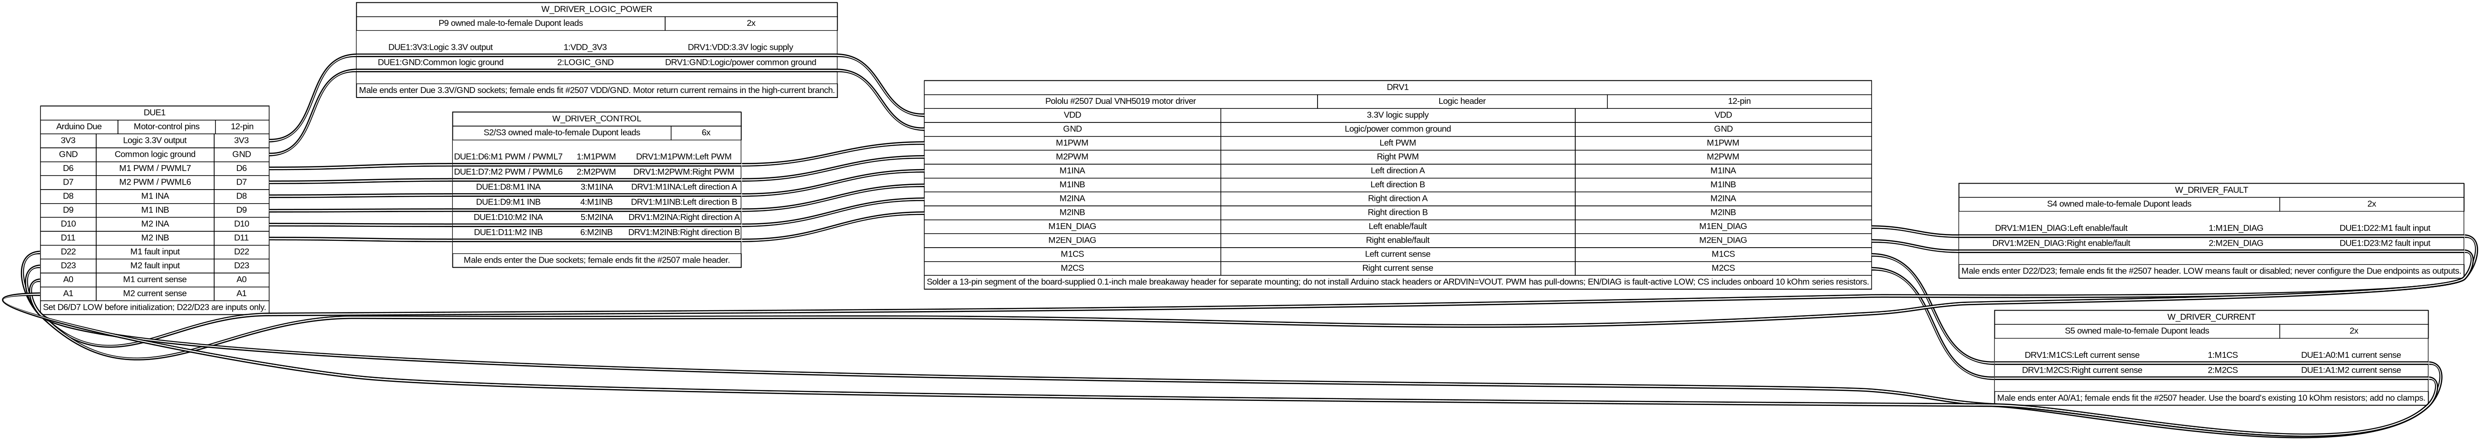
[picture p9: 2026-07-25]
hardware/wiring/control-logic/due-motor-driver.png

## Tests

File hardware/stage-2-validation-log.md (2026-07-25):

# Stage 2B Validation Log

This file records unit-specific evidence for the incremental build defined in
[the phase tracker](../docs/phases.md#stage-2b-incremental-bench-build-and-integration)
and performed with the [assembly guide](../docs/assembly.md).

**Current status:** B1 and B2 were accepted by the owner on 2026-07-25 based
on inspection and testing completed before repository closeout. B3 is next.
Stage 2A selections are not fully bench validated until B1–B28 pass.

## Log Rules

- Work and approve one gate at a time.
- Enter `PASS`, `FAIL`, or `BLOCKED`; do not use an empty observation as proof.
- Record raw readings and the setup that produced them. Do not record only a
  conclusion.
- Identify firmware commits/configurations and CAD revisions used for tests.
- Link photographs by repository-relative path if photographs are retained.
- Preserve failed attempts and corrective actions; append a retest rather than
  erasing evidence.
- A gate may be checked in `docs/phases.md` only after its owner-approval field
  below is complete.

## Build Identity

| Field | Value |
|---|---|
| Build identifier | TBD |
| Primary operator | Nathan |
| Stage 2 start date | 2026-07-25 |
| Firmware path | `software/arduino/diffbot_due/` |
| Commissioning utility | `software/arduino/tools/commission_due.py` |
| Drivetrain CAD revision | TBD |
| Electronics-tier CAD revision | TBD |
| Final Stage 2 mass | TBD |

## Instrument Register

| Instrument | Model/marking | Relevant range or mode | Acceptance/reference result |
|---|---|---|---|
| Bench supply | NICE-POWER `SPS-C3010` | 0–30 V, 0–10 A CC/CV | PASS B2 — previously tested and accepted by owner |
| Multimeter | Model not recorded | DC V, resistance, continuity | PASS B2 — previously tested and accepted by owner |
| IR thermometer | Model not recorded | Temperature and distance-to-spot behavior | PASS B2 — previously tested and accepted by owner |
| Scale | TBD | Robot mass | Pending B14/B27 |
| Calipers/ruler | TBD | Mechanical geometry | Pending B14/B28 |

## Master Gate Status

| Gate | Result | Approval date |
|---|---|---|
| B1 Inventory and evidence baseline | PASS | 2026-07-25 |
| B2 Bench test rig | PASS | 2026-07-25 |
| B3 Due toolchain and safe boot | Pending | — |
| B4 Serial safety foundation | Pending | — |
| B5 PWM commissioning | Pending | — |
| B6 Encoder translator assembly | Pending | — |
| B7 Encoder translator powered test | Pending | — |
| B8 Left encoder hand test | Pending | — |
| B9 Right encoder hand test | Pending | — |
| B10 Motor-driver assembly | Pending | — |
| B11 Motor-driver logic test | Pending | — |
| B12 First powered motor channel | Pending | — |
| B13 First closed-loop and safety test | Pending | — |
| B14 Modular drivetrain deck | Pending | — |
| B15 Second powered motor channel | Pending | — |
| B16 Raised two-channel test | Pending | — |
| B17 Two-channel PI tuning | Pending | — |
| B18 Low-speed floor commissioning | Pending | — |
| B19 Pi-to-Due integration | Pending | — |
| B20 BNO055 acceptance | Pending | — |
| B21 Camera acceptance | Pending | — |
| B22 DROK and dummy-load acceptance | Pending | — |
| B23 Pi header-power and combined-load acceptance | Pending | — |
| B24 Final electronics-tier CAD | Pending | — |
| B25 Final mechanical and wiring build | Pending | — |
| B26 Integrated raised regression | Pending | — |
| B27 Loaded thermal shuttle | Pending | — |
| B28 Close the hardware gate | Pending | — |

## B1 — Inventory and Evidence Baseline

**Result:** PASS — owner-attested acceptance  
**Date/operator:** 2026-07-25 / Nathan  
**Assembly procedure:** [B1](../docs/assembly.md#b1--inventory-and-evidence-baseline)

| Item | Quantity | Exact marking/revision | Connector/assembly state | Condition or blocker |
|---|---:|---|---|---|
| Active baseline | As documented in BOM REV 02 and the Stage 2A records | Owner confirmed the equipment is correct | Owner accepted existing state | No blocker reported |

**Photographs/notes:** Detailed inventory evidence was not requested or
retained; the owner confirmed the equipment is correct and directed B1
closeout.  
**Deviations or corrective action:** None reported.  
**Owner approval:** Nathan — approved 2026-07-25.

## B2 — Bench Test Rig

**Result:** PASS — owner-attested prior testing  
**Date/operator:** 2026-07-25 / Nathan  
**Assembly procedure:** [B2](../docs/assembly.md#b2--bench-test-rig)

| Test | Setup | Expected | Actual |
|---|---|---|---|
| Supply no-load voltage points | Prior owner test | Stable and meter-consistent | PASS per owner; readings not transcribed |
| 10 Ω cold resistance | Prior owner test | Near marked value | PASS per owner; reading not transcribed |
| 2 Ω branch A cold resistance | Prior owner test | Near marked value | PASS per owner; reading not transcribed |
| 2 Ω branch B cold resistance | Prior owner test | Near marked value | PASS per owner; reading not transcribed |
| CC test | Prior owner test | Voltage reduces to hold about 1 A | PASS per owner; readings not transcribed |
| Output enable | Prior owner test | Removes output | PASS per owner |
| IR repeatability | Prior owner test | Repeatable reading | PASS per owner; readings not transcribed |

**Safety/fixture inspection:** Accepted by owner based on prior testing.  
**Deviations or corrective action:** None reported.  
**Owner approval:** Nathan — approved 2026-07-25.

## B3 — Due Toolchain and Safe Boot

**Result:** Pending  
**Date/operator:** TBD  
**Assembly procedure:** [B3](../docs/assembly.md#b3--due-toolchain-and-safe-boot)

| Evidence | Actual |
|---|---|
| Arduino CLI/IDE and SAM core versions | TBD |
| FQBN and Programming USB device | TBD |
| Firmware commit | TBD |
| Compile/upload result | TBD |
| Reset/reconnect observations | TBD |
| Due 5 V rail | TBD |
| Due 3.3 V rail | TBD |
| Startup/disarmed output state | TBD |

**Owner approval:** TBD

## B4 — Serial Safety Foundation

**Result:** Pending  
**Date/operator:** TBD  
**Assembly procedure:** [B4](../docs/assembly.md#b4--serial-safety-foundation)

| Scenario | Expected state | Actual state/result |
|---|---|---|
| Boot | Disarmed/coast | TBD |
| Valid arm/stop/disarm | Defined transition | TBD |
| Valid `SET` at 20 Hz | Watchdog remains fresh | TBD |
| Stop valid `SET` traffic | Zero target/coast after 500 ms | TBD |
| Blank/overlong/malformed input | Rejected; no watchdog refresh | TBD |
| Out-of-range target | Rejected | TBD |
| CSV telemetry logging | Stable and parseable | TBD |

**Firmware/utility commits:** TBD  
**Owner approval:** TBD

## B5 — PWM Commissioning

**Result:** Pending  
**Date/operator:** TBD  
**Assembly procedure:** [B5](../docs/assembly.md#b5--pwm-commissioning)

| Output | Commanded duty | Captured frequency | Captured duty | Reset/disarm LOW |
|---|---:|---:|---:|---|
| D6/M1PWM | 0% | TBD | TBD | TBD |
| D6/M1PWM | Low test | TBD | TBD | TBD |
| D6/M1PWM | 50% | TBD | TBD | TBD |
| D6/M1PWM | 95% | TBD | TBD | TBD |
| D7/M2PWM | 0% | TBD | TBD | TBD |
| D7/M2PWM | Low test | TBD | TBD | TBD |
| D7/M2PWM | 50% | TBD | TBD | TBD |
| D7/M2PWM | 95% | TBD | TBD | TBD |

**Same-controller measurement limitation recorded:** TBD  
**Owner approval:** TBD

## B6 — Encoder Translator Assembly

**Result:** Pending  
**Date/operator:** TBD  
**Assembly procedure:** [B6](../docs/assembly.md#b6--encoder-translator-assembly)

| Inspection | Result/reading |
|---|---|
| Carrier/rail topology | TBD |
| Socket and pin-1 orientation | TBD |
| `DIR`, `/OE`, VCC, GND continuity | TBD |
| A1–A4/B1–B4 mapping | TBD |
| A5–A8 grounded; B5–B8 open | TBD |
| `104` capacitor placement | TBD |
| 5 V-to-3.3 V/Due isolation | TBD |
| Solder-joint inspection | TBD |

**Owner approval:** TBD

## B7 — Encoder Translator Powered Test

**Result:** Pending  
**Date/operator:** TBD  
**Assembly procedure:** [B7](../docs/assembly.md#b7--encoder-translator-powered-test)

| Measurement | Expected | Actual |
|---|---|---|
| Encoder supply | About 5 V | TBD |
| Translator VCC | About 3.3 V | TBD |
| A-side LOW/HIGH | About 0/5 V | TBD |
| B-side LOW/HIGH | About 0/3.3 V | TBD |
| Highest voltage at a Due input | No 5 V exposure | TBD |

**Owner approval:** TBD

## B8 — Left Encoder Hand Test

**Result:** Pending  
**Date/operator:** TBD  
**Assembly procedure:** [B8](../docs/assembly.md#b8--left-encoder-hand-test)

| Trial | Direction | Start count | End count | Delta | Harness movement issue |
|---:|---|---:|---:|---:|---|
| 1 | TBD | TBD | TBD | TBD | TBD |
| 2 | TBD | TBD | TBD | TBD | TBD |
| 3 | TBD | TBD | TBD | TBD | TBD |

**Accepted positive convention:** TBD  
**Owner approval:** TBD

## B9 — Right Encoder Hand Test

**Result:** Pending  
**Date/operator:** TBD  
**Assembly procedure:** [B9](../docs/assembly.md#b9--right-encoder-hand-test)

| Trial | Direction | Right delta | Unwanted left delta | Harness issue |
|---:|---|---:|---:|---|
| 1 | TBD | TBD | TBD | TBD |
| 2 | TBD | TBD | TBD | TBD |
| 3 | TBD | TBD | TBD | TBD |

**Accepted positive convention:** TBD  
**Owner approval:** TBD

## B10 — Motor-Driver Assembly

**Result:** Pending  
**Date/operator:** TBD  
**Assembly procedure:** [B10](../docs/assembly.md#b10--motor-driver-assembly)

| Inspection | Result |
|---|---|
| Board marking/revision | TBD |
| Three terminal blocks | TBD |
| 13-pin general-purpose header | TBD |
| Stackable headers absent | TBD |
| `ARDVIN=VOUT` absent | TBD |
| Joint/bridge inspection | TBD |
| Terminal/header continuity | TBD |
| VIN/GND and output isolation behavior | TBD |

**Owner approval:** TBD

## B11 — Motor-Driver Logic Test

**Result:** Pending  
**Date/operator:** TBD  
**Assembly procedure:** [B11](../docs/assembly.md#b11--motor-driver-logic-test)

| Check | Actual |
|---|---|
| VDD and logic-ground voltage | TBD |
| D6/D7 reset/disarmed state | TBD |
| D8–D11 commanded behavior | TBD |
| D22/D23 with VIN absent | TBD |
| A0 12-bit zero reading | TBD |
| A1 12-bit zero reading | TBD |
| Due reset/USB behavior | TBD |

**Owner approval:** TBD

## B12 — First Powered Motor Channel

**Result:** Pending  
**Date/operator:** TBD  
**Assembly procedure:** [B12](../docs/assembly.md#b12--first-powered-motor-channel)

| Parameter/scenario | Actual |
|---|---|
| Supply voltage/current limit | TBD |
| M1 terminal polarity for positive motion | TBD |
| Encoder sign agreement | TBD |
| EN/DIAG powered-normal state | TBD |
| Low-duty forward/reverse behavior | TBD |
| Unloaded supply current | TBD |
| A0/current-sense plausibility | TBD |
| Coast/disarm/reset behavior | TBD |

**Owner approval:** TBD

## B13 — First Closed-Loop and Safety Test

**Result:** Pending  
**Date/operator:** TBD  
**Assembly procedure:** [B13](../docs/assembly.md#b13--first-closed-loop-and-safety-test)

| Scenario | Target/setting | Result and stop time |
|---|---|---|
| PI low-speed step | TBD | TBD |
| PI reverse step | TBD | TBD |
| Due reset | TBD | TBD |
| Firmware upload | TBD | TBD |
| USB loss/watchdog | 500 ms watchdog | TBD |
| EN/DIAG-low simulation | 1 kΩ to ground | TBD |
| Missing encoder | Low target, wheel raised | TBD |
| Latched-fault reset conditions | Disarmed/zero/cleared | TBD |

**Initial M1 PI and safety parameters:** TBD  
**Owner approval:** TBD

## B14 — Modular Drivetrain Deck

**Result:** Pending  
**Date/operator:** TBD  
**Assembly procedure:** [B14](../docs/assembly.md#b14--modular-drivetrain-deck)

| Measurement/revision | Actual |
|---|---|
| CAD revision/source location | TBD |
| Export paths | TBD |
| Print material/profile | TBD |
| Wheel-center separation | TBD |
| Nominal wheel radius | TBD |
| Caster position/clearance | TBD |
| Deck envelope | TBD |
| Mounted drivetrain mass | TBD |
| Free rotation/fastener/strain-relief inspection | TBD |

**Owner approval:** TBD

## B15 — Second Powered Motor Channel

**Result:** Pending  
**Date/operator:** TBD  
**Assembly procedure:** [B15](../docs/assembly.md#b15--second-powered-motor-channel)

| Parameter/scenario | Actual |
|---|---|
| Supply voltage/current limit | TBD |
| M2 terminal polarity for positive motion | TBD |
| Encoder sign agreement | TBD |
| EN/DIAG powered-normal state | TBD |
| Low-duty forward/reverse behavior | TBD |
| Unloaded current/current-sense plausibility | TBD |
| Coast/disarm/reset behavior | TBD |

**Owner approval:** TBD

## B16 — Raised Two-Channel Test

**Result:** Pending  
**Date/operator:** TBD  
**Assembly procedure:** [B16](../docs/assembly.md#b16--raised-two-channel-test)

| Scenario | Voltage/current | Encoder/current observations | Reset/fault/noise result |
|---|---|---|---|
| M1 only | TBD | TBD | TBD |
| M2 only | TBD | TBD | TBD |
| Matched forward | TBD | TBD | TBD |
| Matched reverse | TBD | TBD | TBD |
| Deliberately unmatched | TBD | TBD | TBD |
| Simultaneous starts/stops | TBD | TBD | TBD |

**Owner approval:** TBD

## B17 — Two-Channel PI Tuning

**Result:** Pending  
**Date/operator:** TBD  
**Assembly procedure:** [B17](../docs/assembly.md#b17--two-channel-pi-tuning)

| Target | M1 measured/error/current | M2 measured/error/current | Stability |
|---:|---|---|---|
| Low forward | TBD | TBD | TBD |
| Medium forward | TBD | TBD | TBD |
| Low reverse | TBD | TBD | TBD |
| Medium reverse | TBD | TBD | TBD |

**Accepted shared/per-channel parameters and rationale:** TBD  
**Owner approval:** TBD

## B18 — Low-Speed Floor Commissioning

**Result:** Pending  
**Date/operator:** TBD  
**Assembly procedure:** [B18](../docs/assembly.md#b18--low-speed-floor-commissioning)

| Item | Accepted value/observation |
|---|---|
| Lane and tether arrangement | TBD |
| Initial/final test speed | TBD |
| Acceleration limit | TBD |
| Deceleration limit | TBD |
| Near-zero coast threshold | TBD |
| Stall arming command | TBD |
| Startup grace period | TBD |
| Minimum encoder progress | TBD |
| Detection interval | TBD |
| Slip/oscillation/stopping behavior | TBD |

**Owner approval:** TBD

## B19 — Pi-to-Due Integration

**Result:** Pending  
**Date/operator:** TBD  
**Assembly procedure:** [B19](../docs/assembly.md#b19--pi-to-due-integration)

| Scenario | Device/port state | Result |
|---|---|---|
| Pi USB enumeration | TBD | TBD |
| Command/telemetry/CSV | TBD | TBD |
| Pi reboot | TBD | TBD |
| USB disconnect/reconnect | TBD | TBD |
| Due reset | TBD | TBD |
| Firmware upload | TBD | TBD |
| Stale-command check | TBD | TBD |

**Owner approval:** TBD

## B20 — BNO055 Acceptance

**Result:** Pending  
**Date/operator:** TBD  
**Assembly procedure:** [B20](../docs/assembly.md#b20--bno055-acceptance)

| Evidence | Actual |
|---|---|
| Board/cable marking and header state | TBD |
| `#2998` revision, captive-lead length, and selected socket label | TBD |
| Hub external-power jack empty and switch behavior | TBD |
| UART wiring and PS1 strap | TBD |
| Hub/`#954` USB enumeration and UART baud | TBD |
| Hub switch off/on recovery | TBD |
| Self-test/system status | TBD |
| Stationary values | TBD |
| Hand-rotation axis response | TBD |
| Observed update behavior | TBD |
| Proposed mounting orientation | TBD |

**Owner approval:** TBD

## B21 — Camera Acceptance

**Result:** Pending  
**Date/operator:** TBD  
**Assembly procedure:** [B21](../docs/assembly.md#b21--camera-acceptance)

| Evidence | Actual |
|---|---|
| Camera/cable marking | TBD |
| 22-pin Pi / 15-pin camera orientation | TBD |
| Detection result | TBD |
| Streaming result | TBD |
| Intermittent/cable test | TBD |
| Accepted view and mounting orientation | TBD |

**Owner approval:** TBD

## B22 — DROK and Dummy-Load Acceptance

**Result:** Pending  
**Date/operator:** TBD  
**Assembly procedure:** [B22](../docs/assembly.md#b22--drok-and-dummy-load-acceptance)

| Item | Actual |
|---|---|
| Exact DROK marking/variant | TBD |
| Input/output-ground relationship | TBD |
| Input voltage/current limit | TBD |
| No-load harness-end set point | TBD |
| Repeated power-cycle range | TBD |
| Fast-transient measurement limitation | TBD |

| Load configuration | Duration | DROK output | Harness-end voltage | Calculated current | Converter/contact temperature trend |
|---|---:|---:|---:|---:|---|
| 10 Ω only | TBD | TBD | TBD | TBD | TBD |
| One 2 Ω only | TBD | TBD | TBD | TBD | TBD |
| Two 2 Ω parallel; 10 Ω absent | TBD | TBD | TBD | TBD | TBD |

**Adjustment secured/covered:** TBD  
**Owner approval:** TBD

## B23 — Pi Header Power and Combined Load

**Result:** Pending  
**Date/operator:** TBD  
**Assembly procedure:** [B23](../docs/assembly.md#b23--pi-header-power-and-combined-load)

| Scenario | Harness-end voltage | Pi warning/reset | Connection temperature | Due/motor result |
|---|---:|---|---|---|
| Pi boot/NVMe | TBD | TBD | TBD | N/A |
| CPU load | TBD | TBD | TBD | TBD |
| Camera + `#2998`/BNO055 + Due + cooler | TBD | TBD | TBD | TBD |
| Both motors start raised | TBD | TBD | TBD | TBD |
| Both motors run raised | TBD | TBD | TBD | TBD |

**USB-C confirmed absent:** TBD  
**`PSU_MAX_CURRENT=5000` enabled/verified only after pass:** TBD  
**Owner approval:** TBD

## B24 — Final Electronics-Tier CAD

**Result:** Pending  
**Date/operator:** TBD  
**Assembly procedure:** [B24](../docs/assembly.md#b24--final-electronics-tier-cad)

| Requirement | CAD provision/revision |
|---|---|
| Pi/NVMe/cooler airflow | TBD |
| Due USB/reset/service | TBD |
| `#2998` switch, ports, and captive-lead access | TBD |
| Driver terminal access/clearance | TBD |
| DROK access and adjustment cover | TBD |
| Source/motor vs logic routing | TBD |
| Strain relief/tie points | TBD |
| BNO055 orientation | TBD |
| Camera orientation/cable | TBD |
| Deferred battery/LiDAR envelope | TBD |

**Owner approval:** TBD

## B25 — Final Mechanical and Wiring Build

**Result:** Pending  
**Date/operator:** TBD  
**Assembly procedure:** [B25](../docs/assembly.md#b25--final-mechanical-and-wiring-build)

| Inspection | Result |
|---|---|
| Print and mounting quality | TBD |
| ALITOVE internal topology | TBD |
| Fuse holder/fuse continuity | TBD |
| Source/motor branch wire and polarity | TBD |
| DROK/Pi branch wire and polarity | TBD |
| Logic/encoder/direct USB/hub/UART/camera routing | TBD |
| Cross-rail isolation | TBD |
| Individual termination tug tests | TBD |
| Service access/strain relief | TBD |

**Final harness photograph/reference:** TBD  
**Owner approval:** TBD

## B26 — Integrated Raised Regression

**Result:** Pending  
**Date/operator:** TBD  
**Assembly procedure:** [B26](../docs/assembly.md#b26--integrated-raised-regression)

| Scenario | Expected | Actual |
|---|---|---|
| Cold start/startup order | Disarmed/coast | TBD |
| Due reset/upload | No unintended motion | TBD |
| Command loss | Ramp to zero/coast | TBD |
| Simulated driver fault | Both coast, latched | TBD |
| Missing encoder | Both coast, latched | TBD |
| Both speed loops/encoders | Stable and independent | TBD |
| Pi/Due power and USB | No warning/reset | TBD |
| BNO055 and camera | Stable | TBD |
| Motor-induced count/data noise | None observed | TBD |
| Connection temperatures | Stable | TBD |

**Owner approval:** TBD

## B27 — Loaded Thermal Shuttle

**Result:** Pending  
**Date/operator:** TBD  
**Assembly procedure:** [B27](../docs/assembly.md#b27--loaded-thermal-shuttle)

**Final Stage 2 mass:** TBD  
**Lane/tether arrangement:** TBD  
**Commanded speed and cycle:** TBD  

| Elapsed min | Ambient °C | M1 case °C | M2 case °C | Driver 1 area °C | Driver 2 area °C | M1/M2 current | Voltage | Fault/reset/performance |
|---:|---:|---:|---:|---:|---:|---|---:|---|
| 0 | TBD | TBD | TBD | TBD | TBD | TBD | TBD | TBD |
| 5 | TBD | TBD | TBD | TBD | TBD | TBD | TBD | TBD |
| 10 | TBD | TBD | TBD | TBD | TBD | TBD | TBD | TBD |
| 15 | TBD | TBD | TBD | TBD | TBD | TBD | TBD | TBD |
| 20 | TBD | TBD | TBD | TBD | TBD | TBD | TBD | TBD |
| 25 | TBD | TBD | TBD | TBD | TBD | TBD | TBD | TBD |
| 30 | TBD | TBD | TBD | TBD | TBD | TBD | TBD | TBD |
| 40 if needed | TBD | TBD | TBD | TBD | TBD | TBD | TBD | TBD |
| 50 if needed | TBD | TBD | TBD | TBD | TBD | TBD | TBD | TBD |
| 60 if needed | TBD | TBD | TBD | TBD | TBD | TBD | TBD | TBD |

**Final 10-minute temperature change:** TBD  
**Stop/acceptance assessment:** TBD  
**Owner approval:** TBD

## B28 — Close the Hardware Gate

**Result:** Pending  
**Date/operator:** TBD  
**Assembly procedure:** [B28](../docs/assembly.md#b28--close-the-hardware-gate)

| Closure item | Accepted revision/result |
|---|---|
| Firmware commit and calibration configuration | TBD |
| Commissioning utility commit | TBD |
| Drivetrain STEP/STL exports | TBD |
| Electronics-tier STEP/STL exports | TBD |
| SolidWorks source location/revision | TBD |
| Final wheel-center separation/radius | TBD |
| Final chassis envelope/mass | TBD |
| URDF update and both xacro expansions | TBD |
| Controller nominal geometry update | TBD |
| ROS package build | TBD |
| Q1–Q11 evidence review | TBD |
| Architecture/matrix evidence-driven changes | TBD |
| B1–B28 approvals complete | TBD |

**Final hardware-gate approval:** TBD

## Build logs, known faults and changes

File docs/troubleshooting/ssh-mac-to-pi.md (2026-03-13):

# Troubleshooting: SSH from Mac to Pi

**Status:** UNRESOLVED as of 2026-03-13
**Symptom:** Mac cannot SSH into Pi at 192.168.68.60. Fails with `No route to host` or times out.

---

## Environment

| Device | Interface | IP | Subnet | MAC |
|---|---|---|---|---|
| MacBook Pro 2021 | en0 (Wi-Fi) | 192.168.68.55 | /22 (255.255.252.0) | — |
| Raspberry Pi 5 | wlan0 | 192.168.68.60 | /22 (255.255.252.0) | 2c:cf:67:dc:5b:d8 |
| Deco router/gateway | — | 192.168.68.1 | — | — |

- Network: TP-Link Deco mesh Wi-Fi
- Pi OS: Ubuntu 24.04 Desktop, ROS 2 Jazzy
- Mac OS: macOS (Darwin 25.3.0)
- SSH user on Pi: `nate`
- Pi hostname: `nate-raspi5` (mDNS: `nate-raspi5.local`)
- DHCP reservation set in Deco app: MAC `2c:cf:67:dc:5b:d8` → 192.168.68.60

---

## Confirmed Working

- Pi has internet access: `ping 8.8.8.8` from Pi → 0% packet loss
- Pi gateway reachable: Pi → 192.168.68.1 ✓
- **Pi → Mac ping: 0% packet loss** (asymmetric — Pi can reach Mac, Mac cannot reach Pi)
- Mac → router (192.168.68.1): works after VPN disconnect
- Pi firewall: `sudo ufw status` → inactive
- Pi wlan0: UP, `192.168.68.60/22`, eth0: DOWN
- Mac ARP entry for Pi: `2c:cf:67:dc:5b:d8` on en0 (correct MAC, valid, not expired)
- Mac route to Pi: via en0, flags UP — route looks correct

---

## Timeline of Attempts

### Session ~2026-03-12 (prior — Desktop, hit context limit)

**Symptom:** SSH from Mac to Pi failing.

**Diagnosis:** Stale ARP cache on Mac.
- `arp -a` showed Pi entry with `expire: -101` (expired)

**Fix applied:** `sudo arp -d 192.168.68.60`
- SSH worked temporarily after this

**Also done:** Set DHCP reservation in Deco app (MAC → IP) to prevent IP drift.

**Outcome:** Temporary fix only. Problem returned.

---

### Session 2026-03-12 (current)

SSH failing again despite DHCP reservation.

**Step 1 — nmap scan from Mac**
```bash
brew install nmap   # nmap not installed
nmap -sn 192.168.68.55/24
```
Result: Only `192.168.68.55` found (the Mac itself). Pi not visible.

**Step 2 — Connected monitor/keyboard directly to Pi**

```bash
ip addr
```
Output: `wlan0: UP, 192.168.68.60/22, brd 192.168.71.255`. eth0: DOWN.

```bash
sudo ufw status
```
Output: inactive

```bash
ip route show default
```
Output: default via 192.168.68.1

```bash
ping -c 4 8.8.8.8
```
Output: 0% packet loss — Pi has full internet.

**Step 3 — Directional ping test**
- Pi → Mac (`ping 192.168.68.55`): **0% packet loss** ✓
- Mac → Pi (`ping 192.168.68.60`): **100% packet loss, "No route to host"** ✗

This asymmetry is the key finding. Pi can reach Mac; Mac cannot reach Pi.

**Step 4 — Checked Mac routing**

```bash
arp -a | grep 68.60
```
Output: `? (192.168.68.60) at 2c:cf:67:dc:5b:d8 on en0 ifscope [ethernet]`
→ ARP entry valid, correct MAC, not expired.

```bash
route get 192.168.68.60
```
Output:
```
route to: 192.168.68.60
destination: 192.168.68.60
interface: en0
flags: UP,HOST,DONE,LLINFO,WASCLONED,IFSCOPE,IFREF
expire: 919
```
→ Route exists, looks correct.

```bash
ipconfig getpacket en0 | grep subnet
```
Output: `subnet_mask (ip): 255.255.252.0`
→ Mac on /22 — same subnet as Pi. No mismatch.

**Step 5 — Discovered VPN was active on Mac**

Deco Advanced Settings checked for client isolation toggle — not found.

Noticed Mac couldn't reach router either. Asked if VPN was active — it was.

After VPN disconnect:
- Mac → router (`ping 192.168.68.1`): **works** ✓
- Mac → Pi (`ping 192.168.68.60`): **still fails** ✗

**Step 6 — Checked Mac network interfaces**

```bash
ifconfig | grep -E "^en[0-9]|inet |status"
```

Key findings:
- en0 is the only active interface (status: active)
- en0 has TWO inet addresses:
  - `inet 192.168.68.55 netmask 0xfffffc00` — LAN address (correct)
  - `inet 10.5.0.2 --> 10.5.0.2 netmask 0xffff0000` — **residual VPN tunnel address** (not cleared after disconnect)
- All other interfaces (en1–en6): status inactive

**Step 7 — SSH attempts (all failed)**
```
ssh rpi                  → No route to host (nate-raspi5.local)
ssh nate@192.168.68.60   → No route to host
ssh nate@192.168.68.55   → Connection refused (that's the Mac itself)
```

Session paused here.

---

### Session 2026-03-13

**Context:** SSH still failing. Resumed troubleshooting.

**Step 1 — Deco app review**

Two Pi-like devices visible in Deco:
- "nate-RasPi5" at .55 — active upload/download traffic
- "Raspi5" at .60 — matches DHCP reservation

Initially suspected Pi had drifted to .55. Tested:
```
ssh nate-raspi5.local  → Undefined error: 0
ssh nate@192.168.68.55 → Connection refused (port 22)
ssh nate@192.168.68.60 → No route to host
```
"Connection refused" at .55 means something is reachable there but SSH not running. Turned out .55 is the Mac itself. "nate-RasPi5" at .55 in Deco is a **stale cached entry** from a previous lease. Deleted from Deco app.

**Step 2 — Confirmed Pi state (monitor/keyboard)**

```bash
sudo systemctl enable --now ssh   # SSH was already running (started 1 day prior)
ip addr show wlan0
```
Output: `inet 192.168.68.60/22`, MAC `2c:cf:67:dc:5b:d8` — confirmed correct. SSH active and listening on 0.0.0.0:22.

DHCP reservation was previously disabled during troubleshooting — **re-enabled** for MAC `2c:cf:67:dc:5b:d8` → .60.

**Step 3 — Confirmed VPN residual cleared on Mac**

```bash
ifconfig en0 | grep inet
```
Output: only `inet 192.168.68.55` — no `10.5.0.2` VPN tunnel address. Mac is clean.

**Step 4 — ARP flush + ping (still fails)**

```bash
sudo arp -d 192.168.68.60 && ping -c 2 192.168.68.60; arp -a | grep 68.60
```
Result: 100% packet loss, "No route to host". No ARP entry repopulated after delete.

**Step 5 — Deco isolation settings checked**

- No "Client Isolation" or "AP Isolation" toggle found
- "Device Isolation" feature exists but Pi was NOT listed as an isolated device

**Step 6 — tcpdump on Pi while pinging from Mac (KEY FINDING)**

On Pi:
```bash
sudo tcpdump -i wlan0 arp
```
Pinged .60 from Mac twice. Result:
- Pi sees **heavy ARP traffic from .55** (Mac scanning subnet — likely background nmap)
- Pi sees its own ARP replies to various requests
- **NO ARP request for 192.168.68.60 from 192.168.68.55 appeared at all**

This confirms: the Mac's kernel never sends an ARP broadcast for .60 onto the wire. The packet is rejected before it reaches the network layer.

**Step 7 — Attempted to clear stale host route on Mac**

```bash
sudo route delete -host 192.168.68.60
```
Output: `delete host 192.168.68.60: not in table` — no stale host route existed.

Ping still fails immediately with "No route to host" even after ARP + route cleared.

---

## Confirmed Working (updated)

- Pi SSH: active, enabled, listening on 0.0.0.0:22
- Pi IP: confirmed .60 with correct MAC via direct observation
- Pi → Mac: works
- Mac → router (.1): works
- No VPN residual on Mac
- No stale host route on Mac
- Pi not in Deco Device Isolation list
- Pi UFW: inactive

---

## Key Finding

The Mac's kernel drops packets to .60 *before* generating an ARP request. The Pi never sees an ARP broadcast from the Mac for .60, even immediately after `arp -d` and `route delete`. This is a Mac-side kernel/routing issue.

---

## Hypotheses (updated, most → least likely)

1. **macOS packet filter (pf) rule blocking .60** — VPN software may have installed pf rules that were not cleaned up on disconnect. pf can block outbound traffic silently, causing immediate EHOSTUNREACH before ARP.

2. **Deco proxy ARP intercepting and swallowing requests** — Deco mesh may be doing proxy ARP for .60 and failing silently (no response forwarded to Pi). Mac sends ARP, Deco intercepts, never forwards, Mac gets no reply and falls back to EHOSTUNREACH. Would explain why Pi sees no ARP requests for .60 while other hosts' ARPs do reach it.

3. **macOS routing table anomaly** — Some other routing entry or flag is causing .60 specifically to be unreachable, even though the /22 network route via en0 looks correct.

---

## Next Steps (in recommended order)

1. **Check Mac pf rules:**
   ```bash
   sudo pfctl -sr 2>/dev/null | grep -E "60|block"
   netstat -rn | grep "68\."
   route get 192.168.68.60
   ```

2. **Ethernet test** — plug Pi into Deco node via ethernet cable. If SSH works over eth0 → Deco WiFi/proxy ARP is the problem.

3. **Check if Deco is doing proxy ARP** — from Mac, after `arp -d 192.168.68.60`, run `arp -a | grep 68.60` immediately after a ping attempt. If an entry appears with the **Deco's MAC** (not Pi's MAC `2c:cf:67:dc:5b:d8`) → proxy ARP confirmed.

4. **Reboot Mac** — fully resets pf, routing table, and any other kernel state.

---

## What We Know Is NOT the Problem

- Pi firewall (UFW inactive)
- Pi IP drift (DHCP reservation re-enabled, Pi confirmed at .60)
- Subnet mismatch (both on /22)
- Pi internet connectivity (works fine)
- Pi SSH service (confirmed running)
- Mac VPN residual (cleared)
- Stale host route on Mac (not in table)
- Deco Device Isolation (Pi not listed)
- Pi ARP responsiveness (Pi does respond to ARP from other hosts)

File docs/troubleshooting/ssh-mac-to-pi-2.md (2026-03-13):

# SSH: Mac → Pi Troubleshooting (2026-03-13)

## Symptom
Mac unable to SSH into Pi. Error: `port 22: No route to host`.

## Environment
- Pi: Raspberry Pi 5, Ubuntu, IP `192.168.68.60/22` (WiFi via wlan0)
- Mac: `192.168.68.55/22` (same subnet, same Deco mesh pod)
- Router: Spectrum SBG8300 in passthrough mode → two TP-Link Deco pods in WiFi Router mode

## What We Checked

### Pi side (all fine)
- `sshd` active, listening on port 22 (`0.0.0.0:22` and `[::]:22`)
- `~/.ssh/authorized_keys` exists, permissions correct (700/600)
- `ufw` was active but had no rules — ran `sudo ufw allow ssh`, confirmed it did nothing useful since ufw status showed **inactive**
- `iptables` empty — no firewall rules at all
- Pi → Mac ping: **100% success**

### Network side (ruled out)
- Both devices on same `/22` subnet — routing not the issue
- Both on same Deco mesh pod — inter-node isolation not the issue
- Deco client isolation: confirmed disabled
- Mac ARP table had Pi's MAC address — Layer 2 working

### Root cause: NordVPN network extension on Mac
- Mac → Pi ping: 100% packet loss, `sendto: No route to host`
- `ifconfig | grep utun` revealed **9 active utun interfaces** — NordVPN's system extension was running even though NordVPN was "disconnected"
- Routing table showed `192.168.68/22` with a **reject route (`!`)** — NordVPN's kernel extension was intercepting all traffic

## Fix Applied
1. Fully quit NordVPN from menu bar (not just disconnect)
2. Restarted Mac

## Permanent Solution: Tailscale
Raw LAN SSH is fragile — subject to IP changes, VPN interference, mesh quirks. Replaced with Tailscale.

### What Tailscale does
- Creates a private WireGuard-based overlay network ("tailnet") across all your devices
- Each device gets a stable `100.x.x.x` IP that never changes regardless of network
- Works through NAT, firewalls, VPNs automatically
- Free tier: up to 100 devices

### Setup on Pi
```bash
curl -fsSL https://tailscale.com/install.sh | sudo sh
sudo tailscale up   # opens auth URL — log in to authorize
tailscale ip        # get Pi's permanent 100.x.x.x address
```

### Setup on Mac
- Download Tailscale from tailscale.com, log into same account
- Add to `~/.ssh/config`:
```
Host pi
    HostName 100.x.x.x
    User nate
    IdentityFile ~/.ssh/id_ed25519
```
- Run `ssh-copy-id pi` for passwordless auth
- Install VS Code "Remote - SSH" extension → connect to `pi` for full remote dev experience

## Result
SSH via `ssh pi` works permanently regardless of NordVPN state, IP changes, or mesh topology.

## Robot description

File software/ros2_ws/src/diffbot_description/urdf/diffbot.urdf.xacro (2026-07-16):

<?xml version="1.0"?>
<robot xmlns:xacro="http://www.ros.org/wiki/xacro" name="diffbot">

  <xacro:arg name="use_ros2_control" default="false"/>
  <xacro:arg name="controllers_file" default=""/>

  <!-- SIMULATION PARAMETERS -->
  <xacro:property name="chassis_length" value="0.25"/>
  <xacro:property name="chassis_width" value="0.18"/>
  <xacro:property name="chassis_height" value="0.06"/>
  <xacro:property name="chassis_mass" value="1.0"/>

  <xacro:property name="wheel_radius" value="0.04"/>
  <xacro:property name="wheel_width" value="0.01"/>
  <xacro:property name="wheel_mass" value="0.05"/>

  <!-- base_link is at the wheel axle centerline. -->
  <xacro:property name="chassis_z" value="${chassis_height / 2.0}"/>
  <xacro:property name="wheel_x" value="${chassis_length / 4.0}"/>
  <xacro:property name="wheel_y" value="0.095"/>
  <xacro:property name="wheel_z" value="0.0"/>

  <xacro:property name="caster_radius" value="${wheel_radius / 2.0}"/>
  <xacro:property name="caster_x" value="${-chassis_length / 4.0}"/>
  <xacro:property name="caster_z" value="${caster_radius - wheel_radius}"/>
  <xacro:property name="caster_mass" value="0.02"/>

  <xacro:macro name="box_inertia" params="mass x y z">
    <inertial>
      <mass value="${mass}"/>
      <inertia ixx="${mass * (y*y + z*z) / 12.0}" ixy="0" ixz="0" iyy="${mass * (x*x + z*z) / 12.0}" iyz="0" izz="${mass * (x*x + y*y) / 12.0}"/>
    </inertial>
  </xacro:macro>

  <xacro:macro name="wheel_inertia" params="mass radius width">
    <inertial>
      <mass value="${mass}"/>
      <inertia ixx="${mass * (3*radius*radius + width*width) / 12.0}" ixy="0" ixz="0" iyy="${mass * radius*radius / 2.0}" iyz="0" izz="${mass * (3*radius*radius + width*width) / 12.0}"/>
    </inertial>
  </xacro:macro>

  <xacro:macro name="sphere_inertia" params="mass radius">
    <inertial>
      <mass value="${mass}"/>
      <inertia ixx="${2.0 * mass * radius*radius / 5.0}" ixy="0" ixz="0" iyy="${2.0 * mass * radius*radius / 5.0}" iyz="0" izz="${2.0 * mass * radius*radius / 5.0}"/>
    </inertial>
  </xacro:macro>

  <!-- BASE LINK -->
  <link name="base_link">
    <visual>
      <origin xyz="0 0 ${chassis_z}" rpy="0 0 0"/>
      <geometry>
          <box size="${chassis_length} ${chassis_width} ${chassis_height}"/>
      </geometry>
      <material name="white">
        <color rgba="1 1 1 1"/>
      </material>
    </visual>
    <collision>
      <origin xyz="0 0 ${chassis_z}" rpy="0 0 0"/>
      <geometry>
          <box size="${chassis_length} ${chassis_width} ${chassis_height}"/>
      </geometry>
    </collision>
    <xacro:box_inertia mass="${chassis_mass}" x="${chassis_length}" y="${chassis_width}" z="${chassis_height}"/>
  </link>

  <!-- WHEEL LINK -->
  <xacro:macro name="wheel" params="name">
    <link name="${name}">
      <visual>
        <origin xyz="0 0 0" rpy="1.57075 0 0"/>
        <geometry>
            <cylinder radius="${wheel_radius}" length="${wheel_width}"/>
        </geometry>
        <material name="black">
          <color rgba="0 0 0 1"/>
        </material>
      </visual>
      <collision>
        <origin xyz="0 0 0" rpy="1.57075 0 0"/>
        <geometry>
            <cylinder radius="${wheel_radius}" length="${wheel_width}"/>
        </geometry>
      </collision>
      <xacro:wheel_inertia mass="${wheel_mass}" radius="${wheel_radius}" width="${wheel_width}"/>
    </link>
  </xacro:macro>

  <xacro:wheel name="left_wheel"/>
  <xacro:wheel name="right_wheel"/>

  <!-- CASTER LINK -->
  <xacro:macro name="caster" params="name">
    <link name="${name}">
      <visual>
        <origin xyz="0 0 0.0" rpy="0 0 0"/>
        <geometry>
              <sphere radius="${caster_radius}"/>
        </geometry>
        <material name="black">
          <color rgba="0 0 0 1"/>
        </material>
      </visual>
      <collision>
        <origin xyz="0 0 0" rpy="0 0 0"/>
        <geometry>
            <sphere radius="${caster_radius}"/>
        </geometry>
      </collision>
      <xacro:sphere_inertia mass="${caster_mass}" radius="${caster_radius}"/>
    </link>
  </xacro:macro>

  <xacro:caster name="caster"/>


  <!-- JOINTS -->
  <joint name="base_link_to_left_wheel" type="continuous">
    <parent link="base_link"/>
    <child link="left_wheel"/>
    <origin xyz="${wheel_x} ${wheel_y} ${wheel_z}" rpy="0 0 0"/>
    <axis xyz="0 1 0"/>
  </joint>

  <joint name="base_link_to_right_wheel" type="continuous">
    <parent link="base_link"/>
    <child link="right_wheel"/>
    <origin xyz="${wheel_x} -${wheel_y} ${wheel_z}" rpy="0 0 0"/>
    <axis xyz="0 1 0"/>
  </joint>

  <joint name="base_link_to_caster" type="fixed">
    <parent link="base_link"/>
    <child link="caster"/>
    <origin xyz="${caster_x} 0 ${caster_z}" rpy="0 0 0"/>
  </joint>

  <xacro:unless value="$(arg use_ros2_control)">
    <gazebo>
      <plugin filename="gz-sim-joint-state-publisher-system" name="gz::sim::systems::JointStatePublisher">
      </plugin>

      <plugin filename="gz-sim-diff-drive-system" name="gz::sim::systems::DiffDrive">
        <left_joint>base_link_to_left_wheel</left_joint>
        <right_joint>base_link_to_right_wheel</right_joint>
        <wheel_separation>${2 * wheel_y}</wheel_separation>
        <wheel_radius>${wheel_radius}</wheel_radius>
        <odom_publish_frequency>30</odom_publish_frequency>
        <max_linear_velocity>0.5</max_linear_velocity>
        <min_linear_velocity>-0.5</min_linear_velocity>
        <max_angular_velocity>1.0</max_angular_velocity>
        <min_angular_velocity>-1.0</min_angular_velocity>
      </plugin>
    </gazebo>
  </xacro:unless>

  <xacro:if value="$(arg use_ros2_control)">
    <ros2_control name="GazeboSimSystem" type="system">
      <hardware>
        <plugin>gz_ros2_control/GazeboSimSystem</plugin>
      </hardware>

      <joint name="base_link_to_left_wheel">
        <command_interface name="velocity">
          <param name="min">-10</param>
          <param name="max">10</param>
        </command_interface>
        <state_interface name="position"/>
        <state_interface name="velocity"/>
      </joint>

      <joint name="base_link_to_right_wheel">
        <command_interface name="velocity">
          <param name="min">-10</param>
          <param name="max">10</param>
        </command_interface>
        <state_interface name="position"/>
        <state_interface name="velocity"/>
      </joint>
    </ros2_control>

    <gazebo>
      <plugin filename="gz_ros2_control-system" name="gz_ros2_control::GazeboSimROS2ControlPlugin">
        <parameters>$(arg controllers_file)</parameters>
      </plugin>
    </gazebo>
  </xacro:if>

</robot>

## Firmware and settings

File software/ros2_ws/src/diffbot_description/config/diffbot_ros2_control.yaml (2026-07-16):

controller_manager:
  ros__parameters:
    update_rate: 100

    joint_state_broadcaster:
      type: joint_state_broadcaster/JointStateBroadcaster

    diffbot_base_controller:
      type: diff_drive_controller/DiffDriveController

diffbot_base_controller:
  ros__parameters:
    left_wheel_names: ["base_link_to_left_wheel"]
    right_wheel_names: ["base_link_to_right_wheel"]

    wheel_separation: 0.19
    wheel_radius: 0.04

    odom_frame_id: odom
    base_frame_id: base_link
    enable_odom_tf: true
    publish_rate: 50.0

    position_feedback: true
    open_loop: false

    cmd_vel_timeout: 0.5
    publish_limited_velocity: true

    linear.x.has_velocity_limits: true
    linear.x.max_velocity: 0.5
    linear.x.min_velocity: -0.5

    angular.z.has_velocity_limits: true
    angular.z.max_velocity: 1.0
    angular.z.min_velocity: -1.0

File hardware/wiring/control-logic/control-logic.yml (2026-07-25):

metadata:
  title: Due, motor-driver, and encoder control logic
  description: "Complete installed control and feedback wiring among the Arduino Due, Pololu #2507, both #4753 encoders, and 74LVC245 translator."
  notes: |
    This diagram covers P8, P9, and S2 through S7.
    Use the owned Mega Prototype Shield V3 as the translator carrier, one #2204 socket, one #735, and owned Elegoo/Dupont leads.
    Logic jumper colors and installed lengths are not yet assigned, so non-factory conductors render neutrally.
    Encoder outputs are 5 V on the translator A side and must never connect directly to the 3.3 V-only Due.
    Driver B motor terminals are not logic ground; motor power wiring is documented separately.

options:
  color_mode: FULL

connectors:
  DUE1:
    type: Arduino Due
    subtype: Installed power, control, and feedback pins
    pins:
      - 5V
      - 3V3
      - GND
      - D2
      - D13
      - D5
      - D4
      - D6
      - D7
      - D8
      - D9
      - D10
      - D11
      - D22
      - D23
      - A0
      - A1
    pinlabels:
      - Encoder 5V output
      - Logic 3.3V output
      - Common logic ground
      - Left encoder A / TIOA0
      - Left encoder B / TIOB0
      - Right encoder A / TIOA6
      - Right encoder B / TIOB6
      - M1 PWM / PWML7
      - M2 PWM / PWML6
      - M1 INA
      - M1 INB
      - M2 INA
      - M2 INB
      - M1 fault input
      - M2 fault input
      - M1 current sense
      - M2 current sense
    notes: Set D6 and D7 LOW before direction/control initialization; D22 and D23 are inputs only.

  DRV1:
    type: "Pololu #2507 Dual VNH5019 motor driver"
    subtype: Logic header
    pins:
      - VDD
      - GND
      - M1PWM
      - M2PWM
      - M1INA
      - M1INB
      - M2INA
      - M2INB
      - M1EN_DIAG
      - M2EN_DIAG
      - M1CS
      - M2CS
    pinlabels:
      - 3.3V logic supply
      - Logic/power common ground
      - Left PWM
      - Right PWM
      - Left direction A
      - Left direction B
      - Right direction A
      - Right direction B
      - Left enable/fault
      - Right enable/fault
      - Left current sense
      - Right current sense
    notes: Solder a 13-pin segment of the board-supplied 0.1-inch male breakaway header for separate mounting; do not install Arduino stack headers or ARDVIN=VOUT. PWM has pull-downs; EN/DIAG is fault-active LOW; CS includes onboard 10 kOhm series resistors.

  ENC_L:
    type: "Left #4753 encoder"
    subtype: Logical view of the shared six-wire motor assembly
    pins: [BLUE, GREEN, YELLOW, WHITE]
    pinlabels: [Encoder +5V, Encoder GND, Encoder A, Encoder B]
    pincolors: [BU, GN, YE, WH]
    notes: "Factory wire colors, not verified cavity numbers. The retained 1x6 female housing may mate a marked 1x6 segment cut from the #2507-supplied male header on the carrier."
    ignore_in_bom: true

  ENC_R:
    type: "Right #4753 encoder"
    subtype: Logical view of the shared six-wire motor assembly
    pins: [BLUE, GREEN, YELLOW, WHITE]
    pinlabels: [Encoder +5V, Encoder GND, Encoder A, Encoder B]
    pincolors: [BU, GN, YE, WH]
    notes: "Factory wire colors, not verified cavity numbers. The retained 1x6 female housing may mate a marked 1x6 segment cut from the #2507-supplied male header on the carrier."
    ignore_in_bom: true

  U1:
    type: "Owned Adafruit #735 74LVC245 octal bus transceiver"
    subtype: "3.3V encoder level translator in #2204 socket on Mega prototype carrier"
    pins: [1, 2, 3, 4, 5, 6, 7, 8, 9, 10, 11, 12, 13, 14, 15, 16, 17, 18, 19, 20]
    pinlabels:
      - DIR / tie to 3.3V
      - A1 / left encoder A
      - A2 / left encoder B
      - A3 / right encoder A
      - A4 / right encoder B
      - A5 / tie to GND
      - A6 / tie to GND
      - A7 / tie to GND
      - A8 / tie to GND
      - GND
      - B8 / leave unconnected
      - B7 / leave unconnected
      - B6 / leave unconnected
      - B5 / leave unconnected
      - B4 / right encoder B
      - B3 / right encoder A
      - B2 / left encoder B
      - B1 / left encoder A
      - /OE / tie to GND
      - VCC / 3.3V
    notes: "Install in one owned #2204 20-pin socket soldered to the owned Mega Prototype Shield V3 after checking its rail layout. Pins 11-14 remain open; DIR HIGH selects A-to-B; /OE LOW enables outputs."
    additional_components:
      - type: "Owned Adafruit #2204 20-pin IC socket"
        qty: 1
      - type: Owned Arduino Mega Prototype Shield V3
        subtype: Translator and encoder fanout carrier
        qty: 1

  C1:
    type: Owned 0.1 uF ceramic capacitor
    subtype: "104 decoupling capacitor"
    pins: [1, 2]
    pinlabels: [VCC side, GND side]
    notes: Mount directly across U1 pins 20 and 10.
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

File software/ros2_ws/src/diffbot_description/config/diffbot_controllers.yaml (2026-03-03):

controller_manager:
  ros__parameters:
    update_rate: 100  # Hz
    use_sim_time: true

    joint_state_broadcaster:
      type: joint_state_broadcaster/JointStateBroadcaster

    diffbot_base_controller:
      type: diff_drive_controller/DiffDriveController

diffbot_base_controller:
  ros__parameters:
    left_wheel_names: ["left_wheel_joint"]
    right_wheel_names: ["right_wheel_joint"]
    wheel_separation: 0.230   # track_width from URDF
    wheel_radius: 0.040       # wheel_radius from URDF
    publish_rate: 50.0
    publish_odom: true
    publish_odom_tf: true
    cmd_vel_timeout: 0.5
    use_stamped_vel: false
    odom_frame_id: odom
    base_frame_id: base_link

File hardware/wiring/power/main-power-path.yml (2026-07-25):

metadata:
  title: Diff-drive robot main power path
  description: Battery through protected distribution, motor-driver and Pi branches, and Pi-to-Due USB.
  notes: |
    Design definition only; these connections are not yet electrically validated.
    P1 battery connector and undervoltage protection remain battery-selection dependent.
    Owned 16 AWG wire, fuse parts, ALITOVE splices, Pi header extender, and jumper leads are assigned below.
    Cable lengths are intentionally omitted until physical component placement is known.

options:
  color_mode: FULL

connectors:
  BAT1:
    type: Future 3S battery
    pincount: 2
    pinlabels: [BAT+, BAT-]
    pincolors: [RD, BK]
    notes: 11.1 V nominal, 12.6 V fully charged; exact battery is not selected.
    ignore_in_bom: true

  J1_BAT:
    type: Future keyed battery connector
    subtype: Battery-side half
    pincount: 2
    pinlabels: [BAT+, BAT-]
    pincolors: [RD, BK]
    notes: Exact polarized connector family is not selected.
    ignore_in_bom: true

  J1_ROBOT:
    type: Future keyed battery connector
    subtype: Robot-side half / manual disconnect
    pincount: 2
    pinlabels: [BAT+, BAT-]
    pincolors: [RD, BK]
    notes: Exact polarized connector family is not selected.
    ignore_in_bom: true

  F1:
    type: Owned waterproof medium inline fuse holder
    subtype: 14 AWG / standard ATO-ATC / 10 A fuse
    pincount: 2
    pinlabels: [IN, FUSED OUT]
    pincolors: [RD, RD]
    loops:
      - [1, 2]
    notes: Install nearest practical point to battery positive; use stripped wire and weatherproof the completed joins.
    additional_components:
      - type: Owned standard blade fuse from 80-piece kit
        subtype: 10 A ATO/ATC
        qty: 1

  TB1_POS:
    type: Owned ALITOVE 3-wire splice connector
    subtype: Fused-positive distribution
    pinlabels: [Fuse output, Driver branch, Converter branch]
    pincolors: [RD, RD, RD]
    pincount: 3
    loops:
      - [1, 2]
      - [1, 3]
    notes: Use one piece only if continuity proves all three selected ports are common; otherwise replace with a known-common 3-port lever connector.

  TB1_NEG:
    type: Owned ALITOVE 3-wire splice connector
    subtype: Battery-negative distribution
    pinlabels: [Battery negative, Driver return, Converter return]
    pincolors: [BK, BK, BK]
    pincount: 3
    loops:
      - [1, 2]
      - [1, 3]
    notes: Use a separate piece from positive. Verify the intended three-port common topology before wiring.

  DRV1:
    type: Pololu Dual VNH5019 motor driver
    subtype: "#2507 power terminal"
    pins: [VIN, GND]
    pinlabels: [VIN, Power ground]
    pincolors: [RD, BK]
    notes: Land stripped 16 AWG copper directly in the supplied 5 mm screw terminal; do not tin wire compressed by the screw.

  PS1:
    type: DROK 5.10 V converter
    pins: [IN_POS, IN_NEG, OUT_POS, OUT_NEG]
    pinlabels: [IN+, IN-, OUT+, OUT-]
    pincolors: [RD, BK, RD, BK]
    notes: Land stripped 16 AWG input wire directly in the screw terminals. Exact-unit input rating and common-ground behavior require bench verification.

  H1:
    type: Owned 2x20 extra-tall female 0.1-inch stacking header
    subtype: 23 mm Pi GPIO extension; four used contacts shown
    pins: [2, 4, 6, 14]
    pinlabels: [5V pin 2, 5V pin 4, GND pin 6, GND pin 14]
    pincolors: [RD, RD, BK, BK]
    notes: One header exposes these contacts through the M.2 HAT+ stack. Confirm actual fit, pin numbering, and jumper gender before power.

  PI1:
    type: Raspberry Pi 5
    subtype: Power header below H1 and direct USB-A host port
    pins: [2, 4, 6, 14, USB_VBUS, USB_D_MINUS, USB_D_PLUS, USB_GND]
    pinlabels: [GPIO 5V, GPIO 5V, GPIO GND, GPIO GND, USB VBUS, USB D-, USB D+, USB GND]
    pincolors: [RD, RD, BK, BK, RD, WH, GN, BK]
    notes: Never connect USB-C power while the DROK header feed is connected.

  DUE1:
    type: Arduino Due
    subtype: Programming micro-USB port
    pins: [USB_VBUS, USB_D_MINUS, USB_D_PLUS, USB_GND]
    pinlabels: [VBUS, D-, D+, GND]
    pincolors: [RD, WH, GN, BK]
    notes: Connect to only one powered USB host.
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

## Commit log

2026-01-19 Revise BOM with updated costs and last updated date
    Updated the last updated date and revised costs for components in the Bill of Materials.
2026-02-17 Add post-tutorial roadmap and Arduino comms decision
2026-02-17 Add BOM PDF
2026-02-19 Add v8 summary: Due as primary MCU, power architecture
    - Arduino Due replaces Mega 2560 as primary motor controller
    - New power architecture section w/ ASCII diagram + voltage table
    - 3.3V logic throughout, zero level shifting needed
    - ESP32 DevKitC as fallback MCU
    - CLAUDE.md points to v8
2026-02-26 Add v9 summary, diffbot_description package, and Foxglove setup
    - Promote project summary to v9 with Feb 26 progress log entry
    - Update CLAUDE.md to point to v9 as source of truth
    - Add diffbot_description ROS 2 package (URDF, launch file, RViz config)
    - Add my_package and py_pubsub tutorial packages from ROS 2 tutorials
    - Document Foxglove Studio as remote visualization solution (replaces VNC/RViz over SSH)
    [diffbot.urdf.xacro]
2026-02-26 Ignore examples and ros_tutorials in src/
    These are cloned repos with embedded .git dirs — not suitable
    for direct inclusion in this repo.
2026-03-03 Complete URDF: wheels, caster, sensor frames, Foxglove launch
    - diffbot.urdf.xacro: full robot model with chassis, left/right drive wheels
    (continuous joints), ball caster (fixed), and sensor placeholder frames
    (lidar, IMU, camera) with correct inertia macros
    - display.launch.py: updated to use foxglove_bridge for visualization
    - package.xml: added foxglove_bridge exec_depend
    [diffbot.urdf.xacro]
2026-03-03 Add Gazebo Harmonic simulation: ros2_control, controllers, launch file
    - diffbot.urdf.xacro: add <ros2_control> block (velocity interfaces for
    left/right wheel joints) and <gazebo> plugin tag for gz_ros2_control
    - config/diffbot_controllers.yaml: joint_state_broadcaster +
    diff_drive_controller configured with correct wheel separation (0.230m)
    and radius (0.040m)
    - launch/gazebo.launch.py: headless Gazebo launch with robot spawn and
    sequential controller loading (robot_state_publisher → gz sim →
    spawn → joint_state_broadcaster → diffbot_base_controller)
    - package.xml: add ros2_control, ros2_controllers, gz_ros2_control,
    ros_gz_sim exec_depends
    - CMakeLists.txt: add config/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
    [diffbot.urdf.xacro, diffbot_controllers.yaml]
2026-03-03 Fix Gazebo launch, add sim quickstart script and docs
    - Fix robot_description YAML parse error (wrap xacro Command in ParameterValue)
    - Switch to IncludeLaunchDescription for gz_sim to load vendor library paths correctly
    - Add clock bridge (/clock) so controller_manager receives sim time
    - Fix cmd_vel schema mismatch: set use_stamped_vel=false so teleop_twist_keyboard works
    - Add scripts/start_sim.sh: one command launches all three tmux windows
    - Add docs/gazebo_sim_quickstart.md: terminal reference and tmux cheat sheet
    [diffbot_controllers.yaml]
2026-03-03 Add Twist→TwistStamped relay; update tmux script and docs
    diff_drive_controller in ROS 2 Jazzy hardcodes TwistStamped with no
    use_stamped_vel parameter. Add scripts/twist_relay.py to relay plain
    Twist from teleop_twist_keyboard to TwistStamped for the controller.
    Update start_sim.sh to launch relay as window 2 and drop the topic
    remap from teleop. Update quickstart doc to reflect 4-window layout.
2026-03-09 Update phases.md: check off Stage 1 complete, add Foxglove + sim items
2026-03-12 Add session logs, CAD STEP files, claude_global; update phases.md
    [37d-gearmotor-50-70.step, pololu-universal-aluminum-mounting-hub-for-6mm-shaft-4-40-holes.step, pololu-wheel-80x10mm-black.step]
2026-03-13 Add troubleshooting doc: SSH Mac→Pi + Tailscale setup
2026-07-16 Complete and document Stage 1 simulation
    [diffbot.urdf.xacro, diffbot_controllers.yaml, diffbot_ros2_control.yaml]
2026-07-25 Document hardware architecture and wiring
    [control-logic.bom.tsv, due-motor-driver.bom.tsv, due-motor-driver.yml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]
